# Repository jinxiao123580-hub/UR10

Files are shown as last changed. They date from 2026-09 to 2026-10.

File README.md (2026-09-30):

# UR10 视觉力觉抓取实验平台

UR10 CB3、Robotiq 二指夹爪、ATI Net F/T 与 Mech-Eye PRO XS 的课程与实验仓库。

**唯一的接手入口是 [`HANDOVER.md`](HANDOVER.md) 顶部的 `0A. 最新接手状态`。** 它覆盖旧
实验记录和历史文档中的结论。

当前版本为 `v2026.09.30`，上一版 `v2026.09.28` 仍保留；本次升级内容、验证边界和恢复说明见
[`docs/18-2026-09-30视觉抓取升级版.md`](docs/18-2026-09-30视觉抓取升级版.md)。

2026-09-24 的视觉自主抓取验收、相机依赖恢复和完整命令见
[`docs/17-视觉自主抓取验收.md`](docs/17-视觉自主抓取验收.md)。

## 仓库结构

| 位置 | 用途 |
|---|---|
| `scripts/` | 采集、规划、真机门禁与执行脚本 |
| `config/` | 标定、工具、附件与网络配置 |
| `ros2_ws/src/` | 数字孪生与 ROS 包完整源码 |
| `third_party/` | 外部 Mech-Eye ROS 包的固定版本补丁与恢复启动文件 |
| `docs/`、`HANDOVER.md` | 当前操作入口、限制与交接说明 |
| `outputs/` | 已版本化的原始数据、计划和实验验证证据 |

## 现在可直接使用

先阅读 [`docs/00-当前可用操作.md`](docs/00-当前可用操作.md)。其中只保留已验收的、当前
环境可运行的命令；所有运动都必须由单独的已验收实验方案授权。

```bash
cd ~/UR10
python3 scripts/diagnose.py
python3 scripts/verify_ur_payload.py
python3 scripts/monitor_ur_safety.py --duration 3
```

相机验证需单独启动相机终端（重启后重新执行）：

```bash
# 终端 A：启动 Mech-Eye
cd ~/UR10
source /opt/ros/humble/setup.bash
source ~/colcon_ws/install/setup.bash
ros2 launch ~/colcon_ws/src/mecheye_ros2_interface/launch/start_camera_ur10.py

# 终端 B：采集并保存验证数据
cd ~/UR10
source /opt/ros/humble/setup.bash
source ~/colcon_ws/install/setup.bash
python3 scripts/validate_mecheye_capture.py
```

## 当前边界

- 不执行电脑端流式 IK 真机运动。
- 不把未独立验证的 ATI 重力补偿用于控制或抓取判定。
- 不运行历史抓放脚本；其负载参数未验证。
- 相机图像虽有颜色话题名，但 PRO XS 的 2D 传感器是单色（硬件规格），实测 bgr8 三通道逐像素相同。
- 视觉物体中心尚未独立验收；已完成的抓放含人工修正，不是自主抓取。
- 保留的抓放示例是 [`scripts/position_pick_place.py`](scripts/position_pick_place.py)，仅为已确认点位的位置控制，不含力控；当前只通过 dry-run，尚未完成本机真机抓放验收。
- 固定点课程演示可显式使用 `--demo`；该模式忽略 `OBJ`，不代表抓取成功，完整重启后指令见 `docs/00-当前可用操作.md`。
- 夹爪实时反馈验证使用 [`scripts/verify_gripper_motion.py`](scripts/verify_gripper_motion.py)，不移动机械臂。

## 文档导航

| 文档 | 当前用途 |
|---|---|
| [`docs/00-当前可用操作.md`](docs/00-当前可用操作.md) | 已验证命令和禁用入口 |
| [`docs/01-硬件与网络.md`](docs/01-硬件与网络.md) | 硬件、网络和端口 |
| [`docs/02-官方ROS2驱动.md`](docs/02-官方ROS2驱动.md) | 官方 ROS 2 驱动启动与只读确认 |
| [`docs/04-夹爪控制.md`](docs/04-夹爪控制.md) | Robotiq ASCII 通道和状态解释 |
| [`docs/08-六维力与3D相机.md`](docs/08-六维力与3D相机.md) | ATI、Mech-Eye 接入和坐标约定 |
| [`docs/09-MechEye相机接入清单.md`](docs/09-MechEye相机接入清单.md) | 相机接入与采集验收 |
| [`docs/11-机器人自身标定.md`](docs/11-机器人自身标定.md) | TCP、负载和运动学标定 |
| [`docs/12-力传感器重力补偿.md`](docs/12-力传感器重力补偿.md) | 重力补偿的失败结论与限制 |
| [`docs/14-待办与已知问题.md`](docs/14-待办与已知问题.md) | 未完成项目的唯一清单 |
| [`docs/15-位置抓放展示流程.md`](docs/15-位置抓放展示流程.md) | 重启后固定点展示的完整终端指令 |
| [`docs/16-历史ROS桥抓放方法.md`](docs/16-历史ROS桥抓放方法.md) | 原样保留的旧 ROS 抓放命令，仅供历史对照 |

`experiments/` 和 `legacy/` 存放历史过程与失败实验，不是操作教程。新结论必须保存原始数据，
经独立验证后才写入 `docs/`。

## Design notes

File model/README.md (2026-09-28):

# 末端模型

本目录是 UR10 仓库中唯一的末端模型源，不依赖本机的 ROS 工作区路径。

| 路径 | 用途 | RViz 状态 |
| --- | --- | --- |
| `solidworks/end_effector/` | 用户从 SolidWorks 导出的完整末端装配：ATI 六轴力传感器、连接件、Robotiq 2F-85（闭合）和 Mech-Eye 相机 STL；另保留原始 STEP。 | 当前 CAD 可视化来源 |
| `collision/ur10_cell.collision.xacro` | 根据实测尺寸建立的简化包络碰撞模型。 | 仅供碰撞/间隙初步检查，不能作为真机安全判据 |
| `ur10/visual/` | UR10 本体七个 DAE 视觉网格副本，与当前 CAD RViz 使用的 URDF 视觉网格完全一致。 | 网页监控台实时模型来源 |
| `ur10/*.stl` | UR10 本体各连杆的碰撞网格副本。 | 离线碰撞/间隙检查备用 |

## 查看完整 CAD

```bash
cd ~/UR10
source /opt/ros/humble/setup.bash
source ~/colcon_ws/install/setup.bash
python3 scripts/build_urdf_with_cad_meshes.py
ros2 launch launch/view_ur10_preliminary_cad.launch.py
```

生成的 `outputs/vision/ur10_preliminary_cad_meshes.urdf` 和其中的 `cad_meshes/` 是可直接由 RViz 载入的副本；源文件始终在本目录。装配相对 `tool0` 的初版安装方向由 `config/robot_attachments.preliminary-cad-20260921.yaml` 固化，当前为已人工确认的 `tool_yaw_deg: 270`。

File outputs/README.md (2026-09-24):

# `outputs/` 证据与可复算数据

本目录保存实验运行产生的证据，不是临时缓存。路径被 JSON 计划和复算脚本引用，请勿随意改名。

| 目录 | 内容 |
|---|---|
| `handeye/` | 手眼标定数据集、图像、角点、同步机器人帧、原始点云与求解报告 |
| `vision/` | 物块识别、棋盘预检、悬停/主动视角原始点云、融合与抓放计划 |
| `ft_*`、`gripper/` | ATI 六轴力、夹爪状态和验证证据 |
| `dashboard/` | 运行时日志；不作为版本化实验输入 |

当前视觉自主抓取的验收入口和各文件含义见
[`../docs/17-视觉自主抓取验收.md`](../docs/17-视觉自主抓取验收.md)。

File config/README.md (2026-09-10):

# ATI gravity calibration data

Calibration date: 2026-09-10 (Asia/Shanghai)

## Files

- `ft_gravity_calibration.yaml`: accepted calibration generated from the last
  10 consistent poses. This is the file consumers should load.
- `ft_gravity_calibration.mixed-18.yaml`: all 18 persisted samples from both
  acquisition batches. It is retained as raw evidence; its combined fit is
  invalid because the first 8 samples are inconsistent with the later batch.
- `ft_gravity_calibration.invalid-20deg.yaml`: earlier 12-pose, 20-degree
  calibration result retained for comparison. It is invalid and must not be
  used for compensation.

## Accepted result

- Downstream mass: `3.2170005989 kg`
- Center of mass in `ft_sensor`: `[-0.0739583, 0.0746015, 0.0594935] m`
- Force bias: `[5.7368001, 7.2738515, 32.9430006] N`
- Torque bias: `[-0.2363989, -0.1070706, -0.2677242] N m`
- Force RMS residual: `0.7986392 N`
- Torque RMS residual: `0.0916483 N m`
- Design condition number: `9.4482`

The ATI hardware bias must remain zero. Gravity compensation must use the
software parameters above. The mass is the load below the sensing element;
it is not the total robot payload including the Net F/T sensor body.

The accepted result is a fit result. Validate it on poses not used by the fit
before enabling collision detection or force control.

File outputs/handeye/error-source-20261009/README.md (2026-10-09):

# 2026-10-09 固定棋盘格误差来源实验

本目录是供离线复算的原始实验记录，不是新手眼标定结果。实验期间棋盘格未移动（现场用户确认）；机械臂只作低速位移，未修改 DH、相机内参或手眼外参。标定文件仍为 `config/handeye_eye_in_hand_20260921.yaml`。

## 数据和顺序

| 顺序 | 数据集 | 有效样本 | 说明 |
| --- | --- | ---: | --- |
| 1 | `dataset.json` | 5 | 首个静止位姿，之后机械臂换位置和姿态 |
| 2 | `pose-change/dataset.json` | 3 | Y 平移实验的起点 A |
| 3 | `translation-only/dataset.json` | 3 | 从 A 纯平移约 +155.19 mm Y，姿态基本不变 |
| 4 | `return-to-pose/dataset.json` | 3 | 低速沿 Y 原路返回 A |
| 5 | `xminus-160/dataset.json` | 3 | 从 A 纯平移约 -159.97 mm X，姿态基本不变 |
| 6 | `x-return/dataset.json` | 3 | 低速沿 X 原路返回 A |

每个数据集旁的 `samples/<sample_id>/` 包含彩色原图 `image.png`、角点图 `corners.png`、原始有组织点云 `cloud.npz`、逐帧 UR 状态 `robot_frames.json` 和 `sample.json`。数据集 JSON 内的 `files` 字段保留采集电脑的绝对路径；在其他电脑上请按**数据集所在目录**寻找同名 `samples/`，不要使用旧绝对路径。仓库的 `scripts/analyze_handeye_closure.py` 已按相对目录读取点云。

## 已复算的观测值

- Y 起点到 +155.19 mm 位：OpenCV PnP 的固定棋盘格基座坐标差 1.420 mm、朝向差 0.3918°；原始深度角点刚体拟合位置差 1.672 mm、朝向差 0.078°。返回位与 Y 起点实际 TCP 相差 0.089 mm / 0.009°，PnP 位置差 0.542 mm，深度位置差 0.426 mm。
- X 起点到 -159.97 mm 位：实际 TCP 朝向差 0.007°；PnP 的固定棋盘格位置差 1.251 mm、朝向差 0.477°。返回位与 X 起点实际 TCP 相差 0.019 mm / 0.009°，PnP 位置差 0.158 mm、朝向差 0.032°，深度位置差 0.216 mm。
- X 侧视角仅约 35–36 个角点有可用深度，且点云角点一致性约 2 mm；该视角深度拟合**不可用于独立精度裁决**。原位三次重复的 PnP 板原点 RMS 通常约 0.008–0.032 mm，这只反映短时重复性，不等于绝对精度。

固定手眼平移在工具朝向不变的纯平移差分中抵消。固定手眼旋转误差可能造成跨视角位置误差，却不能单独解释工具朝向几乎不变时 PnP 棋盘格朝向变化约 0.4–0.5°。仍需核对相机模型、角点检测、深度配准、实体安装与棋盘格平面性；不要由这组数据直接修改 DH 或手眼参数。

## 在另一台电脑复算

从仓库根目录执行（不连接机器人）：

```bash
PYTHONNOUSERSITE=1 /usr/bin/python3 scripts/analyze_handeye_closure.py \
  --dataset outputs/handeye/error-source-20261009/xminus-160/dataset.json \
  --calibration config/handeye_eye_in_hand_20260921.yaml \
  --output outputs/handeye/error-source-20261009/xminus-160/recomputed-closure.json
```

将 `--dataset` 改为表中的其他五组即可；现有 `static-closure.json` 是采集机上的参考输出。对两组的 `static-closure.json`，比较 `board_geometry.reference_base_from_target.matrix_4x4` 的平移差和旋转夹角；不要把静止组内 RMS 当作跨视角误差。旧多姿态基线为 `outputs/handeye/error-source-baseline-20261009.json`，对应已归档的 `outputs/handeye/manual-eye-in-hand-20260921-r2.json`。

依赖为 Python 3、NumPy、OpenCV、SciPy 和 PyYAML。离线脚本不发送运动指令；`motion-result.json` / `return-motion-result.json` 是已经完成的低速返回记录，不应重放。

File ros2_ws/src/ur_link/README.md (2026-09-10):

# ur_link —— 最小 UR ROS2 桥（无需机械臂侧安装任何东西）

把 UR 控制器三个原生 TCP 接口包成 ROS2 节点，适合课程/实验室“先打通”场景：
CB3(固件≥3.5) 与 e-Series 均适用。要 MoveIt 实时规划控制请走官方
ur_robot_driver + externalcontrol URCap(需要示教器侧安装)。

## 接口
| ROS 侧 | 说明 | UR 侧 |
|---|---|---|
| `/joint_states` (sensor_msgs/JointState) | 6 关节 位置/速度/电流 | 30001 Primary @10Hz |
| `/ur_link/is_program_running`, `/ur_link/robot_mode`, `/ur_link/speed_fraction` | 运行/模式/速度系数 | 同上 |
| `ur_link/dashboard/power_on` 等 Trigger 服务 | power_on/brake_release/close_safety_popup/stop/pause/play/robotmode/... | 29999 Dashboard |
| `~/urscript` (std_msgs/String 话题) | 发任意 URScript | 30002 Secondary |

## 构建
```bash
cd ~/ros2_ws
colcon build --packages-select ur_link
source install/setup.bash
```

## 运行
```bash
# 实机
ros2 launch ur_link ur_link.launch.py robot_ip:=192.168.1.3
# 或分开跑：
ros2 run ur_link ur_state_node --ros-args -p robot_ip:=192.168.1.3
ros2 run ur_link ur_command_node --ros-args -p robot_ip:=192.168.1.3
```

## 用起来（示例）
```bash
ros2 topic echo /joint_states --once

# 上电+松刹车（机械臂旁必须有人按住急停随时准备）
ros2 service call /ur_link/dashboard/power_on std_srvs/srv/Trigger
ros2 service call /ur_link/dashboard/brake_release std_srvs/srv/Trigger

# 让它动：发 URScript(先载入任意程序并 play 才有程序上下文；或直接发脚本也会执行)
ros2 topic pub --once /ur_link/urscript std_msgs/String \
  "data: 'movej([0,-1.5708,0,-1.5708,0,0], a=1.4, v=1.05)'"
# 建议先加  sleep(0.5) 等待编译：
ros2 topic pub --once /ur_link/urscript std_msgs/String \
  "data: 'sleep(0.5)\nmovej([0,-1.5708,0,-1.5708,0,0], a=1.4, v=1.05)'"
```

## 离线自测（不需要机械臂）
```bash
python3 ~/ur_learn/scripts/fake_ur_server.py 0     # 模拟 127.0.0.1 的 UR
ros2 run ur_link ur_state_node --ros-args -p robot_ip:=127.0.0.1
ros2 topic echo /joint_states
```

## 注意
- 机械臂没上电/急停/保护性停止时，30002 发的运动命令会被忽略，先看 robotmode。
- e-Series 处于“本地(local)”模式时 30001/30002/30003 断开，改连 30011/30012。
- 老 CB3 固件(<3.5)没有帧头流，本包会退化为尽力解析，仍能读 q_actual。
- 速度/加速度给默认上限以内；始终有人在急停旁。

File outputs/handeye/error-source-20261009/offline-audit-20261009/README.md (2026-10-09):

# 固定棋盘格完全离线复算（2026-10-09）

输入提交：`0489e5d505f3924ae5eb9cd39b791f70de69646e`。20 个有效样本的原图、cloud.npz、sample.json、逐帧状态齐全；91 个输入文件逐一核对 Git blob 与 SHA-256。9512 帧机器人状态通过有限性及均值一致性检查。使用数据集旁 samples/<sample_id>，没有依赖旧 /home/jx 路径。

没有连接、移动机器人，也没有修改现有标定文件。冻结手眼 YAML SHA-256：`7fbd513c5f5b3cf2a9014a16ce5fda77543e12c889420abad3ae864e7665f153`。

## 主要结果

完整过程、误差传播及原始 SB 结果见 [初始报告](results/REPORT.md)，定位敏感性见 [补充报告](results/deeper/INTERPRETATION.md)，冻结参数和时间关联见 [决策报告](results/frozen/DECISION.md)。历史报告中的本机路径为当时运行记录；跨平台复现请用下方入口。

以下使用仅由前三组图像残差选出的 SB + cornerSubPix(9) 固定规则；是回顾性划分，不是未经查看的新数据验证，更不是绝对精度标定。深度为角点附近 7×7 有效 XYZ 中值的独立刚体拟合。单位为 mm / deg。

| 比较 | 控制器 TCP 平移/转角 | 基座棋盘 PnP 变化 | 基座棋盘深度变化 |
|---|---:|---:|---:|
| Y A→B | 155.189 / 0.00579 | 1.538 / 0.21418 | 1.636 / 0.06981 |
| Y A→返回 A | 0.0885 / 0.00907 | 0.471 / 0.04596 | 0.464 / 0.05052 |
| X A→B | 159.971 / 0.00725 | 0.526 / 0.08126 | 0.467 / 0.29352 * |
| X A→返回 A | 0.0190 / 0.00876 | 0.157 / 0.01098 | 0.142 / 0.03283 |

* X 侧视角原始检测仅 35–36 个角点有深度；冻结精化后为 35/35/35，约 59% 棋盘区域有深度。深度姿态对邻域尺寸高度敏感，不是可靠姿态真值。

六组 PnP 组内位置 RMS 为 0.025–0.050 mm，但重复性不代表绝对精度。近似同位姿的三簇在约 16.3 分钟内，PnP/深度分别变化 0.613/0.600 mm；线性时间关联约 0.0375/0.0368 mm/min。时间与运动历史混杂，不能认定热漂移。原图角点场也发生相应移动，不能仅归为 PnP 数值抖动。

### 支持、不能排除、已排除的边界

- 支持：角点定位方法会显著改变姿态推断；X 深度姿态不可靠；返回误差含图像与深度共同变化；当前姿态激励不足（平移外参相关矩阵条件数约 1497）。
- 不能排除：内参/成像偏差、深度上游配准或系统偏差、固定件或棋盘变化、时间/运动历史影响、手眼旋转误差、控制器真实运动学误差。没有外部真值，不能把其中某项确定为唯一原因。
- 已排除（限定范围）：输入缺失、旧绝对路径造成无法复算、归档状态均值计算错误、所核对 cloud XYZ→像素的额外缩放/转换错误。固定手眼平移误差不能单独解释这些近纯平移组的毫米级变化；不等于排除所有手眼误差。

## 最后一项纯数据补查：灰度边线交点

[edge-check.json](results/frozen/edge-check.json) 保留探索性检查：用现有角点只初始化局部方向，直接对灰度剖面求边缘，再拟合两条线并求交点，未调用 cornerSubPix，也未用基座闭合选择参数。

它与冻结角点相差 0.337–0.512 px，各组边线拟合 RMS 0.283–0.538 px，PnP RMS 0.205–0.352 px；Y/X 外移闭合变为 0.814/1.588 mm。这不是更准确的结果：边线估计自身残差大、受局部光度和窗口影响，且初始化并非独立真值。该检查未能提供足够精度的独立角点裁判，不能据此替换冻结结果或归因 DH。保留失败/不确定的检查，避免只报告有利算法。

现有数据还可以继续试检测器或联合拟合，但不会增加物理观测约束；在当前姿态激励、时间混杂和缺少独立真值的条件下，不能可靠分离手眼、运动学和共同成像/固定件误差。不建议继续以同一批闭合残差挑选“最优标定”。

## 可复现命令

先在可联网阶段准备 Python 环境并取得完整仓库；计算阶段完全离线，不运行采集/机器人程序。使用原分析版本可最大程度复现软件差异：Python 3.14.6、numpy 2.5.3、scipy 1.18.1、opencv-python-headless 5.0.0.93、PyYAML 6.0.3。也可用其他兼容版本，但必须记录差异。

```bash
python -m pip install numpy==2.5.3 scipy==1.18.1 opencv-python-headless==5.0.0.93 PyYAML==6.0.3
# 在仓库根目录运行；--work 必须是尚不存在的新目录。
python outputs/handeye/error-source-20261009/offline-audit-20261009/reproduce.py --repo . --work ../UR10-offline-reproduction
```

入口先校验 91 个输入 SHA-256，然后复制输入到新目录并依次运行全部独立复算、敏感性、冻结规则、时间与可辨识性检查。不访问网络，不导入 ROS，不写原始文件或标定。新目录约需 300 MB 空间；输出在 `../UR10-offline-reproduction/offline-audit-0489e5d/results/`。若原始输入被改动，校验失败即停止；请从指定提交恢复到独立副本后重试，不要覆盖个人改动。

仅校验：

```bash
python outputs/handeye/error-source-20261009/offline-audit-20261009/reproduce.py --repo . --work ../unused --verify-only
```

机器可读结果：[逐样本](results/frozen/sample-results.csv)、[往返比较](results/frozen/pair-results.csv)、[完整冻结计算](results/frozen/validation.json)、[时间关联](results/frozen/temporal.json)、[可辨识性](results/frozen/identifiability.json)。原始检测和深度邻域敏感性也全部保留在 results/。

## 下一步采集要求（仅建议，本次未执行）

先做 **15 分钟完全静止对照**，不需要精密仪器，也不需要移动机器人：

1. 固定机器人、相机、棋盘及支架；选深度完整的正视位置，不用 X 侧视角。保持当前标定、TCP 设置和相机参数，不重新标定、不重启、不自动更改曝光策略。
2. 每 30 秒保存一份，约 31 份；完整保存未标记原图、cloud.npz、camera_info、采样窗口全部机器人状态、图像/深度/状态时间戳及窗口起止时间。不要只留角点或平均位姿。
3. 能取得则额外记录曝光、增益、自动曝光开关、温度、TCP offset、关节位置和设备时钟。取不到的字段明确标为缺失，不要补零假装已知。记录是否触碰、振动、灯光变化。
4. 继续使用本文冻结检测规则，比较图像角点场、PnP、深度、机器人状态随时间的共同/分离变化，不以闭合误差重新调参。

若静止时 PnP 和深度共同漂移，优先检查固定件、热/时间及共同成像因素；仅 PnP 变则优先查二维定位/内参；仅深度变则优先查深度通道。若静止足够稳定，再另行安排多轮 Y A→B→A、交错采集及更充分转动激励，分离时间与运动历史。本次结果不授权执行任何机器人运动。

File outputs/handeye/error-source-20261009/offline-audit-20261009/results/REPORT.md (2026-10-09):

# 固定棋盘格误差源离线复算

后续已对同一数据继续定位角点精化、棋盘固定残差图样及点云射线关系，新增证据见 [进一步分析](deeper/INTERPRETATION.md)。原报告的 SB 结果保留作为原始处理链基线；后续处理结果并非新标定。

最新完成了固定参数验证、残差方向和时间关联分析，下一项采集的选择见 [固定方案验证与下一步决策](frozen/DECISION.md)。

已核对 GitHub `jinxiao123580-hub/UR10` 的主分支：获取时头提交为 `0489e5d505f3924ae5eb9cd39b791f70de69646e`，父提交 `055ab43d3b1a21df99e53db21bc084032fa7b80b`，提交说明为 `data: archive 2026-10-09 hand-eye error-source experiments`。本报告所有采集数据均固定到该提交。原有 `UR10` 工作树有未提交改动，未用于产生测量结果。

**结论：数据支持视角相关的角点/PnP 位姿偏差，也支持点云与 PnP 存在不一致；尚不能分离相机模型、棋盘实体几何、深度配准/偏置和实体安装变化。固定手眼平移及固定手眼旋转作为全部异常的唯一来源可排除，物理运动学绝对误差仍不能排除。没有依据修改 DH 或手眼文件。**

## 1. 输入完整性与复算方法

六组共 20 个 accepted 样本：全部 `image.png`、`cloud.npz`、`robot_frames.json`、`sample.json` 均齐全且可解码。原图全部 1280×1024；点云全部 1024×1280×3，有非有限点，但 NPZ 的所有成员均可解压，样本 ID 与数据集一致。9512 帧机器人状态的计数与各 JSON 声明一致，TCP 与关节角数值均有限。每个样本从逐帧 TCP 重算的六维算术均值与归档均值最大差为 0。机器人采样窗口内最大位置偏离均值为 0.04454 mm，最大相对首帧转角为 0.009743°；这些是采样窗口内状态变化，不能代表实体绝对定位精度。算术轴角均值和 SO(3) 均值的最大角差仅 2.77×10⁻⁸°，均值实现不是这里的误差源。

下载的 91 个文件（80 个样本文件及 11 个数据集/配置/源码文件）逐项计算 `SHA1("blob " + 字节数 + NUL + 文件内容)`，全部与指定提交的 Git 树对象一致。详见 `git-blob-verification.json`；SHA256 与大小见 `../download-manifest.json`。点云始终从各 `dataset.json` 同级的 `samples/<sample_id>/cloud.npz` 读取，未使用旧 `/home/jx/UR10/...` 路径。

使用冻结的 `config/handeye_eye_in_hand_20260921.yaml`：`tool0_T_camera` 为该文件的旋转矩阵和平移。文件 SHA256 为 `7fbd513c5f5b3cf2a9014a16ce5fda77543e12c889420abad3ae864e7665f153`；计算前后相同。

主结果的处理链：

1. 从原图重新调用仓库 `detect()` 的 OpenCV 棋盘检测逻辑，全部重新检出 9×6=54 个角点。归档角点仅用于消除棋盘对称的编号翻转，没有用来初始化检测或求解。格长 6 mm，原点为编号第一角点。
2. 使用每帧归档 CameraInfo 的 K 与 D（D 为五个零），独立运行 `SOLVEPNP_ITERATIVE`，重新投影并记录逐角点二维残差。
3. 从逐帧机器人 TCP 重算 A，计算 `C = A · X · B`。组内旋转用 SVD 投影到 SO(3)，平移算术平均。
4. 在每个重检角点周围半径 3 px 的 7×7 点云邻域取有效 XYZ 分量中位数，至少 3 个有效像素才保留该角点；从棋盘物点到这些 XYZ 用带 det=+1 约束的 Kabsch 刚体拟合得到 D，再计算 `C_depth = A · X · D`。拟合没有使用 PnP 的 rvec/tvec。
5. 使用经典 `findChessboardCorners + cornerSubPix` 作检测器对照、IPPE 作平面 PnP 分支对照；检查深度邻域半径 1/2/3/5 px；作 0.05 px 独立像素噪声蒙特卡洛与深度角点 bootstrap。

环境：Python 3.14.6、NumPy 2.5.3、OpenCV 5.0.0（包 5.0.0.93）、SciPy 1.18.1、PyYAML 6.0.3。没有导入/调用 ROS、机器人通讯或运动模块；仅从采集源码 AST 提取 `detect` 数学函数。

## 2. 六组重复性和深度质量

下表全部来自本次原图重检。PnP/深度重复性为各样本相对该组平均板位姿的 RMS，单位 mm/°；不是跨视角准确度。深度/PnP XYZ 差是在相机系比较同一角点位置，不依赖手眼。深度拟合 RMS 是拟合后的内部残差，也不是绝对准确度。

| 组 | 样本/状态帧 | 重投影 RMS 均值 px | PnP 重复性 mm/° | 有效深度角点 | 深度/PnP XYZ RMS mm | 深度刚体拟合 RMS mm | 深度重复性 mm/° |
|---|---:|---:|---:|---|---:|---:|---:|
| initial | 5 / 2023 | 0.2067 | 0.0490 / 0.0071 | 54/54/54/54/54 | 0.640 | 0.191 | 0.0666 / 0.0437 |
| pose-change，Y 起点 A | 3 / 1720 | 0.2998 | 0.0336 / 0.0086 | 54/54/54 | 1.283 | 0.281 | 0.0322 / 0.0651 |
| translation-only，Y 位 B | 3 / 1503 | 0.1682 | 0.0077 / 0.0077 | 54/54/54 | 1.027 | 0.154 | 0.0131 / 0.0231 |
| return-to-pose，Y 返回 / X 起点 | 3 / 1518 | 0.2948 | 0.0357 / 0.0266 | 54/54/54 | 0.953 | 0.252 | 0.0253 / 0.0319 |
| xminus-160，X 位 B | 3 / 1127 | 0.3257 | 0.0292 / 0.0439 | **35/36/36** | **1.993** | **0.512** | **0.0894 / 0.4725** |
| x-return，X 返回 | 3 / 1621 | 0.2917 | 0.0306 / 0.0387 | 54/54/54 | 0.962 | 0.262 | 0.0129 / 0.0347 |

所有单帧重投影 RMS 小于 0.5 px；最大单角点残差为 0.8352 px。低残差只能说明模型在这些观测上的内部拟合，不证明内参、板格长或位姿无偏。

六组 PnP 板原点平均位置（基座系 mm）：initial `[409.956,-56.161,-13.221]`；Y A `[409.939,-58.214,-13.628]`；Y B `[409.492,-58.236,-12.276]`；Y 返回 `[409.797,-58.446,-14.099]`；X B `[409.253,-59.397,-13.480]`；X 返回 `[409.763,-58.606,-14.127]`。完整朝向矩阵、法向、逐样本变换及角点残差可由 `audit.json` 的 `groups.C`、`samples.C`、`samples.residual_px` 复核。

首组到 Y 起点不是纯平移：控制器 TCP 变化 26.174 mm / 14.7945°，PnP 板变化 2.093 mm / 0.2967°，深度板变化 2.063 mm / 0.2272°。该段不能套用纯平移的手眼平移抵消结论。

## 3. Y 与 X 的 A→B→A

“实际 TCP”在这里严格指**采集时控制器报告的 TCP**，不是外部测量的实体真值。X 的 A 是 `return-to-pose`，不能错用早先 `pose-change`，两者已有返回残差。

| 路段 | TCP ΔXYZ mm | TCP 位移 mm / 转角 ° | PnP 板 ΔXYZ mm | PnP 板位置 mm / 转角 ° | 深度板位置 mm / 转角 ° |
|---|---|---:|---|---:|---:|
| Y A→B | [-0.039,+155.189,+0.046] | 155.189 / 0.00579 | [-0.446,-0.022,+1.352] | 1.424 / 0.3955 | 1.673 / 0.0819 |
| Y B→返回 A | [+0.0004,-155.157,+0.027] | 155.157 / 0.00492 | [+0.305,-0.210,-1.823] | 1.860 / 0.3137 | 1.779 / 0.1474 |
| Y A→返回 A | [-0.039,+0.032,+0.073] | **0.0885 / 0.00907** | [-0.142,-0.232,-0.471] | **0.544 / 0.0871** | **0.424 / 0.0656** |
| X A→B | [-159.971,-0.011,-0.048] | 159.971 / 0.00725 | [-0.544,-0.951,+0.620] | 1.259 / 0.4864 | **0.514 / 0.4310†** |
| X B→返回 A | [+159.980,+0.004,+0.032] | 159.980 / 0.00265 | [+0.510,+0.791,-0.648] | 1.143 / 0.4875 | **0.308 / 0.4238†** |
| X A→返回 A | [+0.008,-0.007,-0.016] | **0.0190 / 0.00876** | [-0.034,-0.160,-0.028] | **0.166 / 0.0378** | **0.219 / 0.0634** |

† X B 深度拟合不可靠，数值仅为诊断输出，不可据其较小位置差裁决 PnP、手眼或运动学的准确度。X A 和返回 A 各自均有 54 个有效角点。

板中心与板原点分开计算：Y 去程中心差 1.527 mm，X 去程 1.104 mm；返回中心差 Y 0.531 mm、X 0.167 mm。异常不是单纯选了边缘原点造成。

使用归档角点独立重新解 PnP 后，单样本相对归档的最大差仅 0.000131 mm / 0.000030°，复现 README 的 Y 1.420 mm / 0.391786°、深度 1.6715 mm / 0.078005°，X 1.2509 mm / 0.476544°；返回 PnP 残差为 Y 0.5420 mm / 0.099589°、X 0.1581 mm / 0.031531°，深度位置为 0.4257 / 0.2162 mm。本次原图重检与该结果的小差别主要来自检测器版本/角点变化，详见 `supplement.json`。仓库 `analyze_handeye_closure.py` 也对六组重新执行，输出保存为 `reference-*.json`；它使用归档位姿，不能替代原图重检。

## 4. 对误差来源的判别

| 候选原因 | 判定 | 数据依据与限制 |
|---|---|---|
| 视角相关的角点/PnP 系统偏差 | **支持** | 经典检测器的 X 去程板差变为 0.509 mm / 0.0625°，SB 为 1.259 mm / 0.4864°。X 经典重投影均值 0.1756 px，小于 SB 0.3257 px；Y 起点经典 0.1902 px，小于 SB 0.2998 px。仅换同一原图的角点处理便显著改变姿态，证明估计对检测方法敏感。仍没有经典角点的外部真值，不能宣称它准确或已解决全部误差。Y 经典去程仍有 1.483 mm / 0.2108°。 |
| 相机内参、未建模畸变、色图几何/配准 | **不能排除** | 六组 K 相同、D=0。0.05 px 独立像素噪声只产生约 0.047–0.089 mm / 0.027–0.053° 的单帧 PnP 敏感性，明显小于去程姿态变化；系统相关偏差可更大。共同焦距 +1% 将 Y 去程变为 2.086 mm / 0.3130°，径向 k1+0.01 将 X 去程变为 1.105 mm / 0.6177°。这是敏感性示例，不是这些内参真的错了；零 D 可能因为输出已校正，须核对图像管线。 |
| 深度质量及深度/PnP 不一致 | **支持存在限制** | 相机系角点 XYZ 差为 0.64–1.99 mm，不涉及手眼和机器人。它证明两条测量/模型链不一致，不能仅凭差值断定深度有偏而 PnP 正确。X 深度缺失非均匀，内部刚体残差 0.512 mm、组内角度 RMS 0.4725°，需特别降权。 |
| 深度误差作为全部 PnP 异常唯一原因 | **已排除（算法直接因果）** | 本次 PnP 仅用原图、K、D、棋盘格几何，不读深度。深度无法直接制造该 PnP 的角度变化；若色图生成/配准与深度共享上游处理，上游共同误差仍不能排除。 |
| 固定手眼平移作为纯平移段唯一原因 | **已排除** | 姿态固定时该平移严格抵消；实际姿态差仅 0.0058–0.0073°，即使手眼平移误差为 50 mm，其去程差分贡献也仅 0.0051–0.0063 mm，远小于 1.3–1.7 mm。它在 initial→Y A 的 14.8° 转姿段仍不能排除。 |
| 固定手眼旋转作为全部位置及朝向异常唯一原因 | **已排除“唯一原因”；位置贡献不能排除** | 约 0.5° 外参旋转误差作用于 155–160 mm 相对平移可产生约 1.35–1.40 mm 位置偏差。但同一固定旋转不能消掉近乎固定工具姿态下的板朝向差，数学下界见下一节。 |
| 机械臂实体运动学/绝对定位误差、关节回差、负载挠曲 | **不能排除，尚无独立支持足以定责** | TCP 和 q 都来自控制器，不能互相构成外部真值。返回 TCP 很近说明报告位姿返回较好，不能证明去程实体平移/朝向正确。采集窗口内微动很小，不支持明显运动中采集；静止安装挠曲或模型偏差仍可能。 |
| 本地标称 DH 被软件误用生成这次闭环 | **已排除该实现路径** | 采集器把控制器 TCP 均值直接转矩阵；本次闭环也直接使用归档 TCP，没有调用本地 DH/FK。控制器内部运动学的实体准确度仍未知。 |
| TCP/tool0 定义、安装微动、棋盘不平/格长不准/热漂移 | **不能排除** | `robot_frames.json` 明确记录控制器 TCP 定义；采集器却直接命名为 `base_to_tool0`，未保存当时 TCP offset 的独立证明。若有固定偏置，它会折入等效外参，在恒定朝向差分中仍抵消，不能单独解释朝向差；跨朝向段可有影响。实验以现场“板未移动”为前提，没有实体平面度、6 mm 格长溯源或安装位姿计量。 |
| 旧电脑绝对路径、文件缺失、单位/矩阵重算错误 | **已排除本次实现** | 相对路径读取成功，91 个输入 blob 完全一致，20 个样本完整解码，逐帧均值精确重现，归档角点独立 PnP 重现至数值精度。 |

## 5. 误差传播与深度可信度

令 `A=(R_A,t_A)`、`X=(R_X,t_X)`、`B=(R_B,t_B)`，板原点为 `p=t_A+R_A t_X+R_A R_X t_B`。手眼平移误差的跨帧贡献为 `(R_A2-R_A1) δt_X`，上界为 `2 sin(Δθ_A/2)||δt_X||`。纯平移时为零。故不能从本实验的平移闭环残差反向估计手眼平移。

固定 R_A 时，手眼旋转误差的平移敏感性约为 `||Δt_B|| δθ_X`；约 0.5° 可以产生毫米级残差，但这是可解释能力，不是外参误差的证据。Y 相机估计平移长度与报告 TCP 长度仅差 +0.0248 mm；X 差 -0.4874 mm。固定旋转保长度，不能在理想纯平移条件下消掉长度差；实际 R_A 小幅变化及相机距离形成的小量需计入，所以该长度差提示尺度/视角/实体运动误差，也不能专门归于 DH。

对朝向，旋转测地距离满足：`d(R_C1,R_C2) ≥ d(R_B1,R_B2) - d(R_A1,R_A2)`，固定 X 的左乘/共轭不会改变角距离。Y 原图 PnP 相机板朝向差 0.39460°，工具差 0.00579°，任何固定手眼旋转下板闭环角差至少 **0.38880°**；X 至少 **0.47369°**（0.48094°−0.00725°）。所以仅重调固定外参无法让这套 SB PnP 数据的板朝向一致。剩余角差必须在相机估计、报告/实体工具姿态不符、安装变化或实体板变化中寻找。

0.05 px 独立零均值像素扰动试验是条件敏感性，不是经标定的置信区间；实际重投影残差可能相关，不能直接当成独立角点噪声。深度 bootstrap 也只评估所见角点内部抽样敏感性，不包含统一深度偏置、图像配准偏置和棋盘形变。两条链共享 K、角点位置与板物点，因此深度对照是不同测量通道，并非完全无共同误差的计量真值。

X 深度尤其不稳：半径 1/2/3/5 px 下，X 去程深度朝向差为 **0.674/0.654/0.431/0.377°**，位置差 0.467/0.468/0.514/0.567 mm；单帧邻域调整引起的朝向变化最高约 **0.851°**。角点 bootstrap 单帧角度 RMS 为 **0.301/0.678/0.718°**。相比之下，Y 去程深度位置在这些邻域下为 1.655–1.675 mm，较稳定，朝向为 0.065–0.106°。X 缺失主要集中在棋盘部分列，虽总覆盖跨度仍为 48×30 mm，却非均匀覆盖；不能把“仍有三十多个点”视为充分条件。

IPPE 的低残差分支与迭代 PnP 接近，另一个分支在这些图上的 RMS 至少 0.9408 px，且姿态差数十度；不支持简单的 180° 编号反转或另一个平面分支被误选为这里约 0.4–0.5° 异常的解释。格点局部化、相机模型和实体板几何的连续偏差仍需检验。

Y 返回板残差约 0.54 mm、X 约 0.16 mm，超过许多组内重复性，但不等于绝对准确度，也不独立证明回差：图像/深度漂移、TCP 实体与报告不符、热/安装变化均可造成。每组仅 3 帧（首组 5 帧），不能把短时 RMS 除以根号样本数后宣称已排除系统误差。

## 6. 可复现命令与产物

文件均位于 `D:\项目\机械臂` 下。数据和依赖下载完成后，以下命令只使用本地文件，重算过程无网络、无硬件连接：

```powershell
Set-Location 'D:\项目\机械臂'
python audit_verify.py
python audit_recompute.py
python audit_supplement.py
python audit_reference.py
python audit_export.py
```

`audit_recompute.py` 会覆盖本审计自身的 `results/audit.json` 与 `partial.json`，不修改标定或采集文件。`audit_supplement.py` 输出 `supplement.json`，`audit_reference.py` 输出独立目录中的 `reference-*.json` 和日志。主要依赖已局部安装在 `offline-audit-0489e5d/python-deps`，没有修改全局 Python 环境。

在另一台电脑上先复制本审计目录或按固定提交重新获取数据；若需要安装依赖：

```powershell
python -m pip install --target '.\offline-audit-0489e5d\python-deps' numpy==2.5.3 scipy==1.18.1 pyyaml==6.0.3 opencv-python-headless==5.0.0.93
python audit_download.py
```

`audit_download.py` 是获取阶段工具，当前使用这台电脑已有的 `127.0.0.1:7897` 代理，其他电脑需调整该获取选项。获取阶段与完全离线复算分开；复算脚本不联网。Git blob 校验脚本需要本次隔离仓库中的提交树，也可在任意包含该提交的仓库中改 `repo` 路径。完整数据到齐的标志为 `download-manifest.json`；缺失时脚本等待获取完成而不会跳过样本。

## 7. 下一项最有判别力的实验

**固定机器人与相机，用外部计量的刚性平面棋盘在精密位移台上作板的 A→B→A，复现本次 Y/X 的相对相机视角与图像区域。** 这是建议，未在本次执行。

让棋盘沿与原机器人运动相反的实测向量移动，尽量复现本次的相对距离、视角、图像区域；用量块/位移台和独立 6D 计量确认板的真实平移及转角，棋盘先检查平面度和格长。固定同一 K/D 与色图处理，同时记录 SB、经典角点和深度，增加同位姿重复并交错采集 A/B 以控制时间漂移。精度宜达到 ≤0.05–0.1 mm、≤0.02°，以分辨本次毫米级和约半度的效应。

此时直接比较 `camera_T_board` 与外部测量，不需要手眼和机器人运动学。如果相同图像区域仍出现原有朝向/尺度偏差，便支持相机/角点/板模型；若只深度偏离则支持深度通道/配准；若 SB 与经典分歧重现，优先定位角点局部化；若偏差不重现且外部板计量可信，再进行跟踪实体法兰/相机安装的机器人 A→B→A 计量，以区分运动学与安装挠曲。一次阴性结果也要确认已复现相对成像几何，不能直接宣布相机被排除。

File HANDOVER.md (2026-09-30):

# 交接文档 · UR10 视觉力觉抓取系统

最后更新：2026-09-30。本文只保留当前可用状态；原始数据、失败实验和历史过程在
`outputs/`、`experiments/` 与 `legacy/`。

## 0A. 最新接手状态

### 2026-09-30 升级版本

- 当前标签 `v2026.09.30`，旧版 `v2026.09.28` 保留；详见 `docs/18-2026-09-30视觉抓取升级版.md`。
- 一次完整自动抓取与原始 Fz 接触式放置曾执行完成；另一轮持物到达棋盘上方后因力订阅启动收不到样本而在下降前停止。力采样等待已修复且只读测试通过，尚未复验真机放置。
- 初始定位支持棋盘分块检测与扩大搜索，悬停复拍采用局部点云，转运按物块/棋盘朝向规划并检查模型路径。固定 0.400 m 抓放距离门限已移除；未建模外部障碍仍需现场确认。
- 若仍夹持物块停在棋盘悬停位，不要重跑整套抓取；使用 `scripts/finish_held_cube_place.py` 的持物续放入口，并由脚本复核夹爪状态与位姿。

### 2026-09-24 视觉自主抓取验收（当前入口）

- 当前自动入口为 `FASTDDS_BUILTIN_TRANSPORTS=UDPv4 python3 scripts/auto_cube_pick_place.py --execute`；
  完整前置项与命令见 `docs/17-视觉自主抓取验收.md`。它会先复拍物块；首次/复拍不一致时使用
  三视角点云复核，而不是直接按首次棋盘定位下降。
- 夹取点是用户实测的 tool0 `+Z` 220 mm 夹取中心；当前策略对准**点云物块顶面上方 25 mm**。
  本轮 Robotiq 返回 `OBJ=2` 后才执行搬运。
- 放置为原始 ATI `Fz` 接触式：安全高度起始、2 mm 步进、相对基线突变 `>=8 N` 时 stopj、张开、
  抬离。2026-09-24 实测在第 18 步触发 `10.24 N`，已完成释放和离开；这不使用未验证的重力补偿。
- 棋盘格检测新增抗栅格干扰的裁剪放大回退；预检证据
  `outputs/vision/checkerboard-preflight-fixed-20260924/result.json` 为 54/54，RMS 0.253 px。
- 相机 ROS 的本机直连补丁和启动文件已归档在 `third_party/mecheye_ros2_interface/`；厂商 SDK 2.5.0
  是不可随仓库再分发的外部前置项，恢复脚本为 `scripts/bootstrap_mecheye_workspace.sh`。

### 设备与环境

| 项目 | 当前值 |
|---|---|
| 主机 | Ubuntu 22.04，ROS 2 Humble，用户 `jx` |
| UR10 CB3 | `192.168.1.3`，URSoftware `3.15.8.106339` |
| ATI Net F/T | `192.168.1.2`，RDT UDP `49152`，只允许一个消费者 |
| Mech-Eye PRO XS | `192.168.1.33`，SDK `2.5.0` |
| Robotiq | 机器人 `192.168.1.3:63352`，电脑直控 ASCII |

### 已独立验证的结论

- 官方 `ur_robot_driver 2.14.0` 可在 ROS 2 Humble 启动；工厂运动学文件为
  `config/ur10_factory_calibration.yaml`。录制姿态的 FK 对控制器 TCP 最大偏差
  `0.017312 mm / 0.004694°`；机器人基坐标必须使用 `base`，不能使用 `base_link`。
- Eye-in-hand 棋盘格标定使用 `10×7` 方格、`9×6` 内角点、格长 `6 mm`。Park 解在
  5 个留出样本的闭环 RMS 为 `2.642 mm / 1.051°`，最大 `3.855 mm / 1.837°`；冻结后
  一组独立样本为 `2.614 mm / 0.401°`。参数在
  `config/handeye_eye_in_hand_20260917.yaml`。
- 图像 PnP 与组织点云逐角点验收 54/54 有效，XYZ RMS `0.692 mm`、P95 `1.197 mm`、
  最大 `1.332 mm`。
- ATI 原始数据稳定发布到 `/ft_sensor/wrench_raw`，约 200 Hz；UR 30003/30013 状态约
  125 Hz。Mech-Eye 采集接口正常，但所谓颜色图和纹理点云实测均为单色。
- 一次物块抓起、提升和原位放回曾通过，但使用的是“视觉候选 + 人工修正”。视觉候选到
  人工确认中心的 XY 偏差为 `35.84 mm`，因此自主视觉抓取尚未通过。
- 当前保留的位置式抓放示例为 `scripts/position_pick_place.py`，使用控制器原生 `movel`
  和 Robotiq ASCII，不使用 ATI 或重力补偿；`config/position_pick_place.example.json` 中的
  点位仅用于离线示例。当前只通过 dry-run，尚未完成本机真机抓放验收，真机执行前必须现场重新确认。
- 已完成夹爪独立开合反馈验证：空夹 `POS=3 → 22 → 103 → 191 → 230`，张开回到 `POS=3`，
  目标闭合为 `PRE=255`；完整记录在 `outputs/gripper/motion-verification.json`。
- 2026-09-18 完成一次位置抓放闭环；闭合反馈为 `POS=229 / OBJ=3`，用户现场确认实际夹住后，
  继续完成抬升、搬运、释放和离开。该证据证明位置运动链可执行，但不构成自动 `OBJ=2` 验收。
- `scripts/position_pick_place.py --demo` 是固定点课程演示模式：显式忽略 `OBJ` 并继续位置流程；
  不得把演示结果写成抓取成功，也不使用力控。重启后的完整命令在 `docs/00-当前可用操作.md`。
- 课程展示的完整三终端流程已整理到 `docs/15-位置抓放展示流程.md`。

### 当前严格禁止

- 不执行电脑端流式 IK 真机运动；此前 2 mm 流式实验触发 `C153A0` 保护停。
- 不把 ATI 重力补偿用于力控、碰撞停止或抓取判定。所有现有重力模型均为 `valid: false`；
  新数据只用 `/ft_sensor/wrench_raw`。
- 不运行历史抓放程序；它含未独立验证的 `8.0 kg / [-0.03, 0.03, -0.06]` 负载估计。
- 不把控制器回读的 `3.5 kg / [0, 0, 0.1] m` 当作独立测量结果。
- 不把 Mech-Eye 的颜色话题当作真彩色：PRO XS 的 2D 传感器是单色，属硬件规格而非故障，
  `/mechmind/color_image` 的 bgr8 三通道由 SDK 按 `Blue = Gray, Green = Gray, Red = Gray`
  复制而来。型号证据见 `outputs/camera/model-identification-20260918.json`。

### 当前可直接执行的只读检查

```bash
cd ~/UR10
python3 scripts/diagnose.py
python3 scripts/verify_ur_payload.py
python3 scripts/monitor_ur_safety.py --duration 3
python3 scripts/read_ur_state.py
python3 scripts/check_current_docs.py

# 离线分析（不需要相机/机器人）
python3 scripts/analyze_ft_mass_scale.py          # P0-A：质量尺度 vs 常量力偏置（只读传感器 HTTP + 存档数据）
python3 scripts/analyze_cube_center_error.py      # P0-B：中心误差差向量 + 相机侧符号检查
python3 scripts/test_measure_cube_geometry.py     # 视觉几何离线数值门禁（6/6）
```

相机验证需另开终端（重启后重新执行）：

```bash
# 终端 A
cd ~/UR10
source /opt/ros/humble/setup.bash
source ~/colcon_ws/install/setup.bash
ros2 launch ~/colcon_ws/src/mecheye_ros2_interface/launch/start_camera_ur10.py

# 终端 B
cd ~/UR10
source /opt/ros/humble/setup.bash
source ~/colcon_ws/install/setup.bash
python3 scripts/validate_mecheye_capture.py
```

完整的当前入口见 [`docs/00-当前可用操作.md`](docs/00-当前可用操作.md)。

### 网页监控台（2026-09-18 修复启动/停止语义）

`bash scripts/start_dashboard.sh`（**必须先 `cd ~/UR10`**，脚本用的是相对路径）
起桥 + ATI（+ 可选相机），起完会**自检 `http://127.0.0.1:8080/` 真的应答**才打印地址，
否则打印端口占用与桥日志尾部并以退出码 1 结束。停止用
`bash scripts/start_dashboard.sh --stop`：SIGTERM → 最多 3 s → SIGKILL，并**校验 8080/9090
已释放**才报成功。修复前 `ros_web_bridge.py` 会吃掉 SIGTERM/SIGINT（`rclpy.spin` 在守护线程）、
`--stop` 打印"已停止"却留着进程占端口、启动脚本只看 `pgrep` 不看端口 → 页面"打不开"。
详见 `experiments/2026-09-18-入口可用性审计.md` §3.1。

## 课程进度（机械臂工程实践 8 节）

本轮做**第 1–6 节**；第 7（转盘动态抓取）、第 8（毛笔字）延后，且不采购新硬件。
第 4 节用闭合并拢的**左夹爪指尖代替笔尖**。完整方案与逐节做法见
[`experiments/2026-09-18-八节课实施计划草案.md`](experiments/2026-09-18-八节课实施计划草案.md)。

| 课 | 状态 |
|---|---|
| 1 整体认识 | ✅ 设备清单 + 三条通道已写入 [`docs/01`](01-硬件与网络.md) §7 |
| 2 示教器运动 | ✅ `scripts/read_ur_state.py` 已真机只读实测；示教器操作见 §8 |
| 3 ROS 控制运动 | ⏳ 入口已有（`scripts/position_pick_place.py`，**仅 dry-run**）；阻塞在负载未验证 |
| 4 关节标定 | ⏳ TCP 脚本就绪未采集；100.5 mm 直线实验未做 |
| 5 机器人感知 | ⏳ P0-A（力标定 2 倍矛盾）**已诊断**：是单姿态反推忽略常量力偏置的假象，传感器/换算无误；
  修复与绝对尺度基准**按用户决定延后**；时延测量仍未做 |
| 6 视觉自动抓取 | ⏳ 几何方案已换为"测顶面"并带离线门禁（6/6 通过），但**现场未验收**；
  旧的 35.84 mm 参照本身不成立（见 P0-B） |
| 7 转盘动态抓取 | 延后（现有相机 3D 采集 0.7–1.1 s，慢的是 3D 不是 2D，见计划 §5） |
| 8 毛笔字 | 延后（依赖第 4、5 节） |

## 两个必须先解决的问题 —— 均已定位（2026-09-18 当日做完）

### P0-A · 力标定的 2 倍质量矛盾 —— **已诊断为方法学假象，修复延后**

原问题：6 次独立拟合的质量一致收敛到 **3.20–3.29 kg**，而 2026-09-10 单姿态 `|F|/g` 反推
**6.56 kg**，相差 **2.03 倍**且可重复。

**结论（有数值证据）**：单姿态反推**忽略了传感器系内约 25–36 N 的常量力偏置**，
"`|F|` 与姿态无关且等于 `m·g`"这个前提本身不成立。

- 传感器只读配置（HTTP `192.168.1.2/netftapi2.xml`）：`cfgcpf = cfgcpt = 1000000`
  ⇒ `scripts/ati_netft_node.py:49-50` 的硬编码值**等于该传感器自己的标定值**，单位无误；
  `setbias = 0;0;0;0;0;0` ⇒ 硬件 Bias 全零，"错误 Bias 导致翻倍"不成立；量程 `165/165/495/15/15/15`。
- 68 个存档静态姿态的球面拟合（`F` 必落在半径 `m·g`、球心 `b` 的球面上，**不用 FK、不用安装旋转**）：
  6 个批次独立给出 **m = 3.14–3.51 kg**、`|b| = 24.8–35.8 N`，与既有多姿态拟合一致。
- 否证纯尺度错误：若真是 2 倍尺度错，`|F|` 必须恒定；实测 `|F|` 跨 **12.34–69.58 N（5.64 倍）**，
  单姿态法给出的质量在 **1.26–7.10 kg** 间摆动。

证据：`outputs/ft_calibration/mass-scale-diagnosis-20260918.json`、
`experiments/2026-09-18-力标定2倍质量矛盾诊断P0-A.md`；复现 `python3 scripts/analyze_ft_mass_scale.py`。
**仍开放（延后）**：① ~29.6 N 常量偏置的物理来源未定（零点/线缆侧向力/安装预载/配置残留）——
它不改变尺度结论，但直接违反"无外力应读零"；② 绝对牛顿尺度仍依赖质量基准，
控制器回读 `3.5 kg` 只是旁证、按本文规定不算独立测量。

### P0-B · 第 6 节视觉中心误差 —— **假设被否证，查出 50 mm 符号错误，改为"测顶面"**

原假设：`√(25²+25²) = 35.36 mm` 与实测 35.84 mm 只差 0.48 mm ⇒ 推测"两轴各偏半边长"。

**实测差向量否证该假设**：base 差向量 `(+31.36, -17.36) mm`（模长 35.84 mm），
在棋盘格系是 `(36.22, 13.94) mm` —— 只有模长巧合，分量根本不是 25/25。

**查出的硬错误**：可见竖直侧面在 target `x = +0.0528 m`，而相机原点在 target `x = +0.3641 m`
且光轴朝 `-x` ⇒ 凸体只露朝向相机的面，体心必须在**另一侧**（`x = 0.0278 m`）；
旧 `scripts/locate_cube_near_checkerboard.py` 用"远离棋盘格中心"判方向（本场景物块是沿 **-y** 偏
~110 mm 摆放，该启发式无意义）⇒ **符号反了 50 mm**。另外"50 mm 边长先验"从未被测量验证
（可见侧面 y 实测跨度仅 44.28 mm）；与人工确认点残差在符号修正后仍有 **22.2 mm**，
且与"50 mm 立方体 + 单可见侧面"几何上不自洽 ⇒ **那个人工目测点不能当验收基准**。

**修法已实现**：`scripts/measure_cube_geometry.py`（顶面平面 + 最小外接矩形足印 + 参考站立面，
带硬门禁：覆盖率 ≥0.85、与棋盘格面平行 ≤12°、长宽比 ≤1.10、点数下限；不满足**拒识**；
实测边长 ≠ 标称时单独报 `measured_size_prior_mismatch`；支持原始点云落盘与离线复算）。
离线数值门禁 6/6 通过（含"掠射视角只见侧面**必须拒识**"）：
`python3 scripts/test_measure_cube_geometry.py`。
证据：`experiments/2026-09-18-视觉中心误差差向量诊断P0-B.md`、`outputs/vision/center-error-diagnosis-20260918.json`。
**仍未验收**：需现场采集（**必须落盘原始点云**）+ ≥3 个重新摆放位置的**独立真值**比对。

## 已排除，不要再查（省时间）

| 嫌疑 | 结论 |
|---|---|
| 点云单位 mm/m 混用（1000× 错误） | **排除**：实测 `xyz_median ≈ 0.259`，与工作距离 0.3–0.6 m 同量级 ⇒ 是米 |
| 米制尺度完全未验证 | **部分已验**：6 mm 格长即独立长度基准，"逐角点 RMS 0.692 mm"已把尺度误差约束到 ~1.4%；缺的是全视场量程的独立基准 |
| 用了非官方 ROS 驱动 | **排除**：官方英文文档话题表漏了 `color_image` 是**笔误**；中文页与源码均确认该话题是官方的 |
| `base` 与 `base_link` 相差 1.182 m 是平移 | **改为**：UR 官方《Robot Frames》明确两者**同位置、仅绕 Z 轴转 180°**；180° yaw 使半径 r 处点位移 **2r**，r≈0.591 m ⇒ 正好 1.182 m。现场 `tf2_echo base base_link` 可确认 |

## 下一步（按顺序）

1. **P0-A 已诊断、按用户决定延后**：2 倍矛盾是单姿态反推忽略 ~29.6 N 常量力偏置的假象，
   尺度无需修正。延后的是"偏置的物理来源"与"绝对牛顿尺度的独立质量基准"。
2. **P0-B 已定位并实现修法**：下一步是**现场验收**——同一帧看到棋盘格与物块采集并落盘原始点云，
   在 ≥3 个重新摆放位置用独立真值比对（`scripts/measure_cube_geometry.py --capture --save-cloud`）。
3. **时延测量**：全库 grep `延迟|时延|latency|时间同步|时间戳对齐` **零命中**，
   而第 5 节明确要求"特别注意数据时间上的延迟"。
4. 第 4 节：TCP 标定 → 100.5 mm 直线实验
   （⚠️ 纯平移的 `movel` 下，TCP 定义误差**不改变**笔尖位移量 —— 该实验检验的是**运动学精度**，不是 TCP 定义）
5. 第 5 节：重力补偿重新建模 + 独立验收。⚠️ **原计划的门禁要改**：
   "拟合质量须与单姿态 `|F|/g` 一致（<5%）"**数学上无效**（单姿态法忽略了偏置，见 P0-A），
   应改为"未参与拟合的多姿态残差 + 姿态方向覆盖（可辨识性）"双门禁。
6. 第 6 节：P0-B 的几何修法 → 多位置中心误差验收（独立真值）→ 才可接自动抓取
7. **相机服务待定性**：2026-09-18 实测 `/device_info`、`/capture_color_image` 与
   `scripts/validate_mecheye_capture.py` 均无响应（40–60 s 超时，重启相机节点无效），
   相机硬件与 ROS 服务机制本身正常；需在**普通终端**复核一次再定性，见
   `experiments/2026-09-18-入口可用性审计.md` §3.2。

所有新的运动方案遵循：资料依据 → 离线数值门禁 → 官方假硬件 → 单段低速真机 → 完整流程。
每一层保存数值证据。

## 资料与存档规则

- 所有结论必须有数值证据；失败实验写 `experiments/`，原始 CSV/JSON 写 `outputs/`。
- 只有独立验证通过的稳定结论才能写入 `docs/`。
- 更新脚本、接口、路径或有效操作方式时，同一提交中更新 `docs/00-当前可用操作.md`、本文件和
  相关专题文档，并运行 `python3 scripts/check_current_docs.py`。
- 新方案实施前先查官方文档、论文或原始实现，记录来源、版本、适用条件及本机差异。

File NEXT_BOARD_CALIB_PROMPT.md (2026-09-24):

# 新会话用 Prompt：UR10 眼在手上棋盘格标定（重标 + 独立验收）

> 用法：把下面 `===== PROMPT 开始 =====` 与 `===== PROMPT 结束 =====` 之间的全文
> 复制到新对话里作为第一条消息。它是自包含的：新会话不需要看这段对话的历史。

===== PROMPT 开始 =====

我在做 UR10 机械臂工程实践课程的第 5 节（机器人感知），本轮任务是**眼在手上（eye-in-hand）
棋盘格手眼标定：重新标定 + 独立验收**。请先只读摸清现状，再按下面的门禁推进。

## 0. 先读这三个文件（不要假设旧文档里的"已完成"仍然有效）

1. `~/UR10/HANDOVER.md` 顶部「0A. 最新接手状态」——**唯一权威状态**，含「当前严格禁止」清单；
2. `~/UR10/docs/00-当前可用操作.md` —— 当前可执行入口；
3. `~/UR10/experiments/2026-09-18-视觉中心误差差向量诊断P0-B.md` —— 视觉几何的已知错因（必读，
   里面那条 50 mm 符号错误很容易在新代码里重犯）。

## 1. 设备与已验证现状

| 项目 | 值 |
|---|---|
| 主机 | Ubuntu 22.04 + ROS 2 Humble，用户 `jx`，仓库 `~/UR10` |
| UR10 CB3 | `192.168.1.3`，URSoftware `3.15.8.106339` |
| Mech-Eye PRO XS | `192.168.1.33`，SDK `2.5.0`，SN `RAM35238A3020004`（**2D 传感器是单色**，`/mechmind/color_image` 是灰度复制，不是故障） |
| ATI Net F/T | `192.168.1.2`，RDT UDP `49152`，**单消费者**（同时只能一个实例收流） |
| 棋盘格 | `10×7` 方格、`9×6` 内角点、格长 `6 mm` |
| 已有标定 | `config/handeye_eye_in_hand_20260917.yaml`（Park 解，`tool0_from_camera`，15 训练 + 5 留出；留出闭环 RMS `2.642 mm / 1.051°`，最大 `3.855 mm / 1.837°`；冻结后独立样本 `2.614 mm / 0.401°`） |
| **棋盘格位置** | **今天（2026-09-18）已被移动过** ⇒ 旧标定的绝对坐标不再对应现场，必须重标 |
| 机械臂位姿 | 当前 TCP ≈ `(0.647, -0.268, 0.276) m`，看不到旧场景；需要现场用**示教器**把臂点动到能同时看到棋盘格与物块的位姿 |

## 2. 硬性约束（违反即停）

- **禁止**电脑端流式 IK 真机运动（历史上触发过 `C153A0` 保护停）。
- **禁止**运行历史抓放程序（含未独立验证的 `8.0 kg / [-0.03,0.03,-0.06]` 负载估计）。
- **禁止**把 ATI 重力补偿用于力控、碰撞停止或抓取判定（所有现有模型 `valid: false`）。
- **禁止**把控制器回读的 `3.5 kg / [0,0,0.1] m` 当作独立测量结果。
- ATI 需要 RDT 数据时只允许**一个** `scripts/ati_netft_node.py` 实例；仪表盘在跑就会占着流。
- 真机运动前的顺序：**资料依据 → 离线数值门禁 → 官方假硬件 → 单段低速真机 → 完整流程**，
  每层保存数值证据。
- 采集期间机器人必须**静止**：脚本自带门禁 `max_position_motion_mm ≤ 0.5`、
  `max_rotation_motion_deg ≤ 0.2`，超限必须丢样本重采。
- 证据规则：**失败写 `experiments/`，原始 CSV/JSON/点云写 `outputs/`，只有独立验证通过的
  稳定结论才进 `docs/`**。
- **可能有另一个 agent 在同一仓库并行工作**：开工前跑 `git log --oneline -5` 与
  `ps aux | grep -E "codex|ros2|python3"` 看一眼；若它在给机器人发指令，**不要同时动**；
  也避免与它同时改 `HANDOVER.md` / `docs/00` / `README.md`（今天的提交就是它做的）。

## 3. 开工前必须先做的三项检查（全部只读）

```bash
cd ~/UR10
python3 scripts/diagnose.py                     # 网络/端口/模式，期望全绿
python3 scripts/read_ur_state.py                # 期望 robotmode RUNNING / safetystatus NORMAL
python3 scripts/check_current_docs.py           # 结束时也要跑
```

**相机链路必须先确认（今天已知异常）**：我在 2026-09-18 实测
`ros2 service call /device_info`、`/capture_color_image` 与
`python3 scripts/validate_mecheye_capture.py` 全部**超时无响应**（40 s / 60 s），
重启相机节点无效；相机硬件本身正常（SDK 日志显示已连上相机并打印型号/序列号），
ROS 服务机制也正常（本地自检服务可正常应答）。见
`experiments/2026-09-18-入口可用性审计.md` §3.2。存在两种可能：真实链路故障，
或仅是我那次运行环境（只读沙箱，SDK 报 `No write permission for directory /var/log/`）导致。

所以你要做的第一件事是**在普通终端复现**：

```bash
# 终端 A
cd ~/UR10 && source /opt/ros/humble/setup.bash && source ~/colcon_ws/install/setup.bash
ros2 launch ~/colcon_ws/src/mecheye_ros2_interface/launch/start_camera_ur10.py
# 终端 B
cd ~/UR10 && source /opt/ros/humble/setup.bash && source ~/colcon_ws/install/setup.bash
python3 scripts/validate_mecheye_capture.py
```

- 若**仍超时**：先把现象、日志（`~/.ros/log/…`、SDK 输出）、复现命令写进
  `experiments/2026-09-18-相机采集链路不通.md`，**不要**跳过这步硬上标定。
- 若**正常**：把它记进实验记录，然后继续第 4 步。

## 4. 标定流程（按顺序做，每步留数值证据）

1. **布置与基准**
   - 棋盘格固定在台面（平放或倾斜都可，但需同一帧内可见、不反光、不被相机/夹爪自遮挡）。
   - 用尺量方格实长（验证打印比例：应 ≈ `6 mm`，记录实测值与量具）。
2. **采集**
   - 复用现有脚本：`python3 scripts/collect_handeye_sample.py …`（看 `--help` 取参数）。
   - 采 **≥20 个样本**，姿态**分布要散**：平移至少覆盖 3 个位置、朝向至少 3 个不同方向
     （只有平移或只有旋转会退化，手眼解会不稳）。
   - 每个样本落盘到 `outputs/handeye/samples/<id>/`：`image.png` + `sample.json`
     ——**务必同时保存原始点云/中间量**（09-17 只存摘要，导致无法离线复核，是那次最大的证据缺口）。
3. **求解**
   - `python3 scripts/solve_handeye_checkerboard.py …`：Park 解 **+ 与 Horaud（或 Tsai）交叉比对**；
     报设计矩阵条件数、训练残差、留出残差。
   - 留出集固定 **≥5 个样本**，且必须**不参与**求解。
4. **独立验收**
   - 冻结 yaml 之后**再采一组新样本**（完全不参与拟合），报平移/旋转误差；
   - 另外做**固定棋盘格闭环**：同一世界点在多个姿态下的重投影/闭环一致性；
   - 两项都要给数字，不给"看起来对"。
5. **落文档**
   - 全部门限通过 → 写 `docs/`（手眼章节）+ 同步 `docs/00` 与 `HANDOVER.md`
     （注意与并行 agent 的冲突：改前先 `git status` 看有没有别人刚改）。
   - 未通过 → 写 `experiments/`，并把 `valid: false` 与失败数值写进 yaml。
6. **收尾**：`python3 scripts/check_current_docs.py` 必须通过。

## 5. 判据（写进结论，不达标就是 `valid: false`）

| 项目 | 门限 |
|---|---|
| 留出集闭环 平移 | RMS ≤ 3 mm、最大 ≤ 5 mm |
| 留出集闭环 旋转 | RMS ≤ 1°、最大 ≤ 2° |
| 冻结后独立样本 | 平移 ≤ 5 mm、旋转 ≤ 2° |
| 交叉方法差异（Park vs Horaud/Tsai） | 平移 ≤ 1 mm、旋转 ≤ 0.5° |
| 标定板重投影 | RMS ≤ 0.5 px |

## 6. 关键坑（都是本仓库踩过的，别重犯）

1. **单可见侧面推物体中心时，偏移方向由"相机在哪一侧"决定**（凸体只露朝向相机的那个面）。
   旧脚本 `scripts/locate_cube_near_checkerboard.py` 用"远离棋盘格中心"判方向，
   在 2026-09-17 的实测里**差了 50 mm**（可见侧面在 target `x=+0.0528 m`，相机在 `x=+0.3641 m`）。
2. **尺寸先验必须实测验证**：09-17 把"50 mm 标称边长"硬编码进推算，而实测可见跨度只有
   `44.28 mm`，先验本身没被验证过。
3. **原始点云/中间量必须落盘**，只存摘要等于没存。
4. **不要用 `ros2 node list` 判断节点是否启动**：本机实测它返回空，而 `ros2 topic list`
   正常；用 `ros2 topic list` / `ros2 service list` / `ps`。
5. 相机是**单色**（PRO XS 硬件规格），别把 `bgr8` 三通道当彩图。
6. 多网卡环境（有线 + 无线 + tun）：相机 SDK 会抱怨
   "Failed to obtain the IP address of the computer Ethernet port connected to the device"，
   但会按 IP 直连成功——该警告本身不代表故障。

## 7. 顺带要做（同一轮，视觉几何闭环）

标定完成后，用本轮已经做好的新工具做**物块中心测量验收**（这才是第 6 节的实际前置）：

```bash
# 现场：相机已启动、机器人静止，同一帧同时看到棋盘格与物块
python3 scripts/measure_cube_geometry.py --capture \
  --save-cloud outputs/vision/clouds/cube-<tag>.npz \
  --output outputs/vision/cube-measurement-<tag>.json
# 之后可离线复算（不需要相机/机器人）：
python3 scripts/measure_cube_geometry.py --npz outputs/vision/clouds/cube-<tag>.npz
```

- 该工具用**顶面平面 + 最小外接矩形足印 + 参考站立面**算中心，带硬门禁（覆盖率 ≥ 0.85、
  与棋盘格面平行 ≤ 12°、长宽比 ≤ 1.10、点数下限），**不满足就拒识**，
  并且会把"实测边长 ≠ 标称 50 mm"单独报成 `measured_size_prior_mismatch`。
- 它的离线数值门禁已通过 6/6（含"掠射视角只见侧面必须拒识"）：
  `python3 scripts/test_measure_cube_geometry.py` →
  `outputs/vision/measure-cube-offline-selftest-20260918.json`。
- **验收要求**：在**≥3 个重新摆放位置**各测一次，用**独立真值**（钢板尺/卡尺实测，
  或顶面+侧面交叉解算，或落点后的接触点）比对，报告误差分布。
  **不要**再用 2026-09-17 那次"人工目测纠正点"当基准——它与任何单侧面重建都不自洽
  （残差 22.2 mm，见 P0-B 记录）。

## 8. 交付物清单

- `config/handeye_eye_in_hand_<日期>.yaml`：`valid`、方法、训练/留出样本数、各项残差、
  验收门限与结论、`validation_failures`（失败时逐条写数值）。
- `outputs/handeye/samples/<id>/`：图 + JSON + **原始点云/中间量**。
- `outputs/vision/clouds/*.npz` + `cube-measurement-*.json`（多位置验收）。
- `experiments/2026-09-<日期>-眼在手棋盘格重标定.md`：过程、数值、失败也写。
- 若相机链路不通：`experiments/2026-09-18-相机采集链路不通.md`。
- 结束时 `python3 scripts/check_current_docs.py` 通过。

先给我一份"现状核对 + 你打算怎么采（姿态数量与分布）+ 预计风险"的简短计划，
我确认后再开始采样本。

===== PROMPT 结束 =====

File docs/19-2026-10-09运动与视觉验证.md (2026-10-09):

# 2026-10-09 运动与视觉验证

本页记录本次发布的代码修复和现场证据。它不修改 UR10 出厂 DH 参数，也不把相机测量当作外部计量设备的精度认证。上一版 `v2026.09.30` 保留。

## 代码变化

- 监控台冷启动等待真实 HTTP 应答，桥进程提前退出时立即报错，不再依赖固定的两秒等待。
- 自动抓取子进程统一使用系统 NumPy/SciPy，避免本机 `~/.local` NumPy 与系统 SciPy 混用；单独启动的网页监控台不受此环境变量影响。
- 主动视角采点云时，对短暂服务超时做有限重试；超时视角不读取同名旧报告。报告文件带本次采集 ID；多视角合并检查当前采集状态、时间、角度、中心一致性，并允许同一次运行中已稳定的悬停观测参与合并。
- 定量 `movel` 脚本改用可用的 UR 30013 状态流，增加 `--dry-run`、低速/距离限制、机器人状态、关节限位、奇异性及模型自碰撞预检、启动前状态复核和运动后停稳检查。模型不包括全部工作台与线缆；真机运动仍需现场监看。

上述代码通过 Python 编译和 `start_dashboard.sh` shell 语法检查；监控台冷启动、主动视角离线归档及一次低速定量运动曾在本机分别验证。**本次修改后的完整自动抓放流程尚未重新完成真机端到端验收。**

## 2026-10-09 定量运动与棋盘格复核

- 定量移动脚本的一次 `base` 坐标系 Y +100 mm 低速执行，控制器目标/回读终点差 0.140 mm，记录在 [`relative-y-plus-100mm-20261009.json`](../outputs/vision/relative-y-plus-100mm-20261009.json)。这只是控制器内部一致性，不是外部实测误差。
- 另一次由操作者确认的 Y +100 mm 移动，前后各拍两张固定棋盘格。四组原图和相机结果分别见 [`preflight`](../outputs/vision/board-motion-validation-preflight-20261009/result.json)、[`before-repeat`](../outputs/vision/board-motion-validation-repeat-20261009/result.json)、[`after`](../outputs/vision/board-motion-validation-after-yplus100mm-20261009/result.json)、[`after-repeat`](../outputs/vision/board-motion-validation-after-repeat-20261009/result.json)。原图与各 `result.json` 同目录，供重新检测和复算。
- 移动前两张原程序漏检；对图像 ROI `(560,230)–(850,350)` 做 CLAHE 和 3 倍放大后，均检出完整 9×6 内角点。移动后两张直接检出。四次 PnP RMS 为 0.291、0.272、0.317、0.335 px；依据 6 mm 方格求得相机相对棋盘格的位置变化为 `[+6.792, -99.878, -0.880]` mm（棋盘格坐标系），长度 **100.113 mm**。
- 移动前复拍位置差 0.155 mm，移动后复拍差 0.327 mm。100.113 mm 与名义 100 mm 的差值不能解释为机械臂绝对误差 0.113 mm；还存在相机内参、方格实物尺寸、角点/PnP、手眼和姿态变化等误差。
- 用现有 `tool0_from_camera` 手眼旋转和移动后读取的 UR 位姿估算，相机位移在 `base` 中约为 `[-1.247,+100.101,+0.862]` mm，距 +Y 约 **0.868°**，横向分量约 1.516 mm。UR 姿态不是与四张图严格同步记录；两端视觉姿态估计还相差约 0.2°。因此这只是相机位移方向估计，**不能判定机器人 Y 轴本身偏转 0.868°**。

## 后续使用边界

不要据此修改出厂 DH。若要定量判断法兰方向精度，应对每张图同步记录关节角与法兰位姿，扣除相机安装偏置在姿态变化时带来的位移，并在多位置重复。现有固定棋盘格适合工作区相对验证；要认证绝对毫米级精度仍需独立计量基准。

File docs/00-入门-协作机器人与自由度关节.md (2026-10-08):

# 00 · 入门基础：协作机器人 / 自由度与关节

> 这是本仓库 `docs/` 里"使用说明"之外补上的**基础概念教程**。
> 目的是先讲清楚"UR10 是什么、机械臂怎么转"，再去读 `01-硬件与网络.md`、`03-机械臂控制.md` 等操作文档。
> 如果你已经能上手操作，这篇可以当速查。

---

## 1. UR10 是什么

UR10 是丹麦优傲机器人（Universal Robots，下称 **UR**）公司的**六轴协作机械臂**（cobot）。
UR 的经典产品线按负载/尺寸从小到大为 **UR3、UR5、UR10、UR16**；后来升级为 **e 系列**
（UR3e / UR5e / UR10e / UR16e）和更晚的 UR20 / UR30。

**UR10 的核心规格（CB3 代，本仓库设备）**：

| 参数 | 数值 |
|---|---|
| 轴数 / 自由度 | 6 轴（6 自由度），与人手臂类似 |
| 有效负载 | 10 kg |
| 工作半径 | 1300 mm |
| 重复定位精度 | ±0.05 mm（±0.10 mm 标称范围中有差异，以官方数据表为准） |
| 自重 | 约 33.5 kg |
| 控制柜 | CB3（本仓库是 CB3 代，软件 PolyScope URSoftware 3.15.8） |
| 协作特性 | 力/力矩受限、碰撞检测、安全区域可配置，可无护栏与人协同 |

本仓库实测的 UR10 序列号 `2022300602`，即属于 CB3 代。注意 **UR10 与 UR10e 不是同一款**
——e 系列是后一代（更高精度、力传感器增强、新的示教器），本仓库的配置与参数按 CB3 的 UR10 记。

在线数据表与介绍（取回页面时标注为不确定的均以官方最新为准）：

- UR 官网产品页：https://www.universal-robots.com/products/ur10-robot/
- UR DH 参数官方文章：https://www.universal-robots.com/articles/ur/application-installation/dh-parameters-for-calculations-of-kinematics-and-dynamics/

> ⚠️ **本仓库的操作文档（`docs/01`）记录的 IP、端口、标定结论都是针对"这台" UR10 的实测值**，
> 先读通本篇基础，再对照实测，不要拿通用资料里的数值覆盖本机标定结果。

---

## 2. 协作机器人（cobot）是什么

传统工业机器人大多要求装进 **安全围栏/安全光栅**，人机隔离。协作机器人（collaborative robot）
重点解决"让人和机器人**共享工作空间**"：

- **负载与速度可配置受限**：因为力/力矩一般不大，撞到人能伤害有限；
- **碰撞检测**：关节力矩超限或检测到外力时触发保护性停止（Protective Stop）；
- **力受限模式 / 拖动示教（手动牵引）**：可双手拖着机械臂走出轨迹，记录路径再回放；
- **安全区域（Safety Plane）**：在示教器上画禁区，进入即停。

UR 属于典型协作机器人。但协作不等于"绝对安全"——装了重负载、高速、尖锐工具后同样要隔离评估。

> 🖼 **协作机器人示意**（此图是 Yamaha 展品，仅用于示意"能在人附近作业的 cobot"，不是本仓库的
> UR10，型号以 `docs/01` 实测为准）：
>
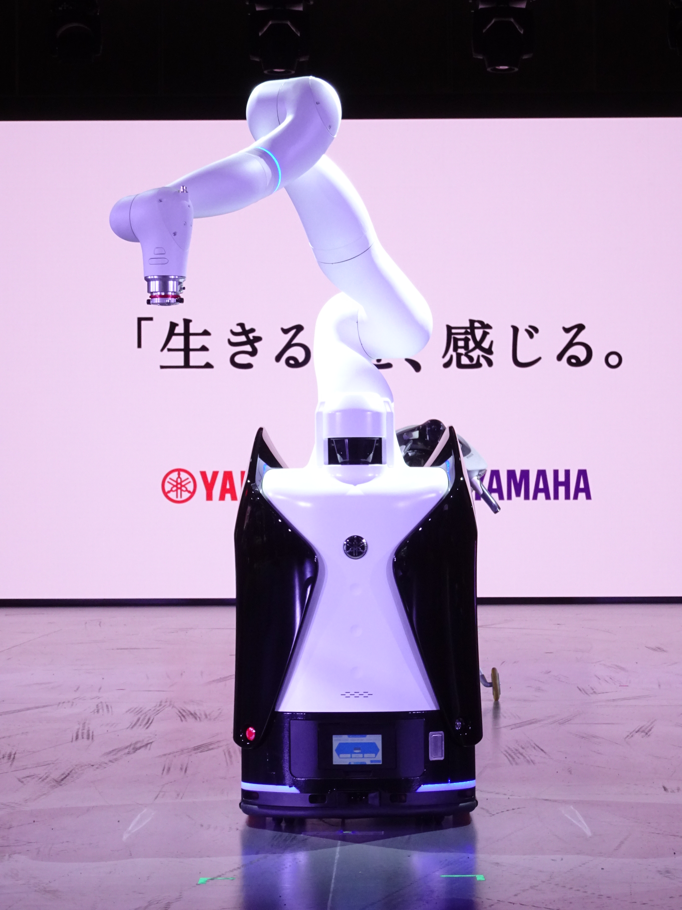
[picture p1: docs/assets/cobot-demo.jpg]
协作机器人示意图
> 
> 图源：[Wikimedia · File:Japan-Mobility-Show-2023-RuinDig 586.jpg](https://commons.wikimedia.org/wiki/File:Japan-Mobility-Show-2023-RuinDig_586.jpg)，
> 作者 RuinDig/Yuki Uchida，授权 **CC BY 4.0**。

本仓库的机器人末端装了 **Robotiq 夹爪 + ATI 力传感器 + 3D 相机**（见 `docs/01`），
重心明显偏置，因此**松刹车/上电前必须先扶住或确认姿态稳定**（`docs/01` 已强调）。

---

## 3. 六轴机械臂：自由度（DoF）

**自由度（Degree of Freedom, DoF）** 指机械臂独立可控的关节数。
六轴机械臂 = 6 个关节，一般用来在三维空间里**任意摆出"位置 + 姿态"**（共 6 个独立量：
3 个平移 + 3 个旋转）。

> 🖼 **6 自由度示意**（三个平移 + 三个旋转，CC BY-SA 4.0，作者 GregorDS）：
>
> 6 自由度示意图
> 图源：[Wikimedia · File:6DOF.svg](https://commons.wikimedia.org/wiki/File:6DOF.svg)，
> 授权 [CC BY-SA 4.0](https://creativecommons.org/licenses/by-sa/4.0/)。UR10 的自由度就是这 6 个
> （沿 x/y/z 移动 + 绕 x/y/z 转动）。

用人来类比：
- 3 自由度（如多数移动扫地机）：只能平面上前后左右转，够不到高，朝向也有限；
- 5 自由度：多数位置能到，但**姿态有约束**，某些朝向到不了；
- **6 自由度（UR10）**：空间中绝大多数点位 + 姿态都能到达，是通用装配/抓放/打磨的最低标准；
- 7 自由度（如部分高级协作臂）：冗余，可在固定末端位姿下改变"肘部"位置（避障/人体学）。

UR10 的 6 个关节从底盘到末端依次习惯命名为：

| 关节 | 名称 / 位置 | 大致对应人的部位 | 在仓库里的称呼 |
|---|---|---|---|
| Joint 1（J1） | 底座 / 基座旋转 | 腰 | 底座旋转 |
| Joint 2（J2） | 肩关节 | 肩 | 上臂摆动（大臂） |
| Joint 3（J3） | 肘关节 | 肘 | 前臂摆动 |
| Joint 4（J4） | 腕 1（沿小臂轴向旋转） | 腕部旋转 | 腕关节一组 |
| Joint 5（J5） | 腕 2（俯仰） | 腕部俯仰 | 腕关节一组 |
| Joint 6（J6） | 腕 3（末端工具旋转） | 手旋转 | 腕关节一组 |

**J4–J6 三个关节交于（近似同一个点的）"球腕"（spherical wrist）**，这是 UR 系列的典型结构，
正/逆运动学有现成解析解（见 `00-入门-运动学`）。

---

## 4. 关节运动范围与工作空间（workspace）

- **关节运动范围（Joint limits）**：UR10 每轴有转角限制（例如 J1 ±360°、J2 -360°~+360° 等，
  以官方数据表为准）。不要只按 `[-180°,180°)` 假设——本仓库 `docs/01` 实测到
  **控制器报告的关节角是连续角**，`J4 = -233.547°` 也是合法值。做限位/插值时用控制器原始值，
  **不要先归一化**（归一化会让插值路径反向绕行）。
- **工作空间（workspace）**：UR10 可达半径约 1.3 m，近似一个"球冠"（球缺）形状，
  但不是完整球——受关节限制、奇异位形、自碰撞约束，底座附近和身体正下方常常受限。
- **奇异位形（singularity）**：某些姿态下机械臂丧失某些方向的自由度（如大臂完全伸直、
  球腕对齐），表现为"末端想直线走但关节突然急剧加速"。见 `00-入门-运动学`。

---

## 5. 关节空间 vs 笛卡尔空间（两条"命令语言"）

这是理解所有机械臂操作的核心分界。`docs/01` 第 8 节已给出示教器上的两种点动方式，
这里补理论：

### 5.1 关节空间（Joint Space）
用 **6 个关节角**（`q = [q1, q2, q3, q4, q5, q6]`）描述机械臂状态。
- 优点：定义简单，不会"跑出可到范围"；接近关节限位、奇异位形的行为可控。
- 缺点：末端具体走到哪、朝向怎么变，**不直观**（要脑内"想一想"）。

UR 里关节角单位常用**弧度**，但示教器/URScript 也常用度。本仓库 `read_ur_state.py`
读 `q_actual`（关节角）、`tool_vector_actual`（TCP 位姿），详见 `docs/01`。

### 5.2 笛卡尔空间（Cartesian Space / Pose Space）
用 **末端工具的中心点（TCP）的位置 + 姿态**描述机械臂状态（见 `00-入门-坐标系与位姿`）。
- 优点：直观——"TCP 走到 (x,y,z)，朝向是斜向下 45°"。
- 缺点：机械臂内部其实没有"凭空" 6 个笛卡尔马达，必须由控制器**解运动学**（IK，见 `00-入门-运动学`）
  反推出 6 个关节角才能动；遇到奇异位形/无解姿态会失败。

> 一句话记忆：
> **关节空间 = 拧哪几个马达；笛卡尔空间 = TCP 在三维世界里走到哪、朝哪。**
> 示教器上"Move/点动笛卡尔"和本仓库的控制脚本本质都是：给目标位姿 → IK 解出关节角 → 伺服执行。

---

## 6. 一台完整的 UR 机械臂由什么组成

| 组成 | 作用 | 本仓库对应 |
|---|---|---|
| **机械臂本体（arm）** | 6 个关节马达 + 减速器 + 连杆 + 末端法兰 | UR10 本体 |
| **末端法兰（flange）** | 装工具的安装法兰，即 `flange` 坐标 | 法兰 → ATI 力传感器 |
| **控制柜（control box, CB3）** | 运行 PolyScope，执行程序、做运动学计算、跑安全层 | CB3 |
| **示教器（teach pendant / Polyscope 触摸屏）** | 人机界面：编程、点动、看状态、设置系统 | 随柜触摸屏 |
| 末端执行器（end effector） | 夹爪、吸盘等"手" | Robotiq 2F 夹爪 |
| 外围传感器 | 力/力矩、视觉 | ATI Net F/T、Mech-Eye PRO XS |

本仓库的"电脑"并不是机械臂的一部分，而是通过 IP 网络驱动它（见 `docs/01`、`docs/02`）。

---

## 7. 一套入门必看的知识链路

建议读文档顺序：

1. 本篇（协作机器人与自由度/关节）→ 知道"几个轴、怎么转"；
2. `00-入门-坐标系与位姿` → 知道"TCP/坐标系/姿态怎么表示"；
3. `00-入门-运动学` → 知道"位置和姿态怎么换算成关节角"；
4. `00-入门-TCP与末端与负载` → 知道"装了工具后中心点变成什么、重心在哪"；
5. `00-入门-PolyScope与URScript` → 知道"程序上怎么让机械臂动"；
6. 再回头读仓库 `docs/01`（本机实测网络/端口/标定）、`docs/03`（机械臂控制）。

---

## 8. 参考与进一步阅读

- UR 官网 UR10 产品页：https://www.universal-robots.com/products/ur10-robot/
- UR 官方协作安全介绍与安全手册：https://www.universal-robots.com/articles/safety-security/
- UR 官方 DH 参数：https://www.universal-robots.com/articles/ur/application-installation/dh-parameters-for-calculations-of-kinematics-and-dynamics/
- UR Academy 免费课程（中文入口）：https://academy.universal-robots.com/cn/

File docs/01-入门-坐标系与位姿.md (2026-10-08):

# 01 · 入门基础：坐标系与位姿

> 读这篇之前先看 `00-入门-协作机器人与自由度关节`。
> 这一篇讲清"位置 (position)"和"姿态 (orientation / pose)"在 UR 里是怎么表示的，
> 以及 base / flange / tool0 / TCP / 工具坐标系这些名词到底指什么。

---

## 1. 为什么机械臂需要"坐标系"

机械臂的 6 个关节角只能告诉我们**马达转到哪**，但要让机器人"把夹爪送到桌子上那杯水的正上方、
朝向向下"，我们需要建立一个**三维参考系**来描述空间位置和朝向。这个参考系就是坐标系（frame）。

UR 把空间里每一个"有名字、有原点、有朝向"的三维直角坐标系叫一个 **frame**。
`x` 向前、`y` 向左、`z` 向上（都是右手系，`x × y = z`）。

---

## 2. 几个关键 frame（UR 官方定义）

下面这张表是 UR ROS2 驱动文档（`ur_description`）中定义的 KDL/URDF 运动链，以及它们和
示教器（Polyscope）显示值的关系：

```
base_link
 ├ base            ← 与 base_link 同位置，但绕 Z 轴旋转 180°，与示教器 "Base" 参照一致
 └ base_link_inertia   （仅惯性/网格挂载用，运动学上等同 base）
    └ shoulder_link
       └ upper_arm_link
          └ forearm_link
             └ wrist_1_link
                └ wrist_2_link
                   └ wrist_3_link
                      └ flange
                      └ tool0
```

| frame 名 | 位置/含义 | 重要提示 |
|---|---|---|
| **base / base_link** | 底座坐标系，"世界"的锚点 | 示教器把某个参照设为 **Base** 时，读到的位姿就是相对 base |
| **flange** | 末端法兰（装工具的那个圆盘）中心 | 给自定义工具/ttool 挂载用；也是"机械臂摆出工具0位姿"的参考 |
| **tool0** | 正运动学算出的"工具坐标系"（工具全 0 配置时的 TCP） | 当系统工具设为"全 0"时，`tool0` ≈ 示教器显示的 TCP |
| **base_link** | 运动链根节点（遵循 REP-103：全零关节配置时臂朝向为 +X） | 与 base 同原点、差 180°，**做 TF 对比示教器数值时不能混用** |

> ⚠️ 重要差异（UR 官方 ROS2 文档明确提醒）：
> ROS/TF 里常用 `base_link`，但**示教器上读的位姿参照是 `base`**（绕 Z 轴转 180°）。
> 拿 ROS 里的 `tool0`-w.r.t-`base_link` 去和示教器"Base 参照 + 全 0 工具"的读数直接对，
> 会差一个 180° 方向的偏置。本仓库 `docs/01` 里"TCP 位姿读数要与示教器对照"时，用的就是
> 示教器自己的 `base` 约定。

---

## 3. 位置（Position）与姿态（Orientation / Pose）

一个"位姿"（pose）= **位置 + 姿态**，共 6 个独立量，对应 6 自由度。

### 3.1 位置：三个平移量
`(x, y, z)`，单位米，相对某个参照 frame 的原点。

### 3.2 姿态：三种常见表示法

| 表示法 | 内容 | 特点 / 在 UR 的使用 |
|---|---|---|
| **欧拉角 RPY（roll/pitch/yaw）** | 绕 X/Y/Z 依次转 `(rx, ry, rz)` | 直观；但**顺序敏感**、有万向节锁（gimbal lock）。UR 示教器状态里常见 RPY（单位弧度） |
| **旋转矩阵 R** | 3×3 方向余弦矩阵 | 适合做数学运算，不直观 |
| **四元数（quaternion）** | `(qx, qy, qz, qw)` | 无万向节锁、便于插值，是 ROS `geometry_msgs/Quaternion` 的格式 |

> 🖼 **欧拉角示意**（α-β-γ，CC BY 3.0，作者 Lionel Brits）——同一个姿态用连续三次旋转表示，
> 旋转**顺序**不同结果就不同，这正是 3.3 要强调的点：
>
> 欧拉角示意图
> 图源：[Wikimedia · File:Eulerangles.svg](https://commons.wikimedia.org/wiki/File:Eulerangles.svg)，
> 授权 [CC BY 3.0](https://creativecommons.org/licenses/by/3.0/)。

UR 的 URScript 里 `p[x, y, z, rx, ry, rz]` 就是"位置 + RPY"。本仓库 `read_ur_state.py`
读到的 `tool_vector_actual` 即这种 **TCP 位姿矢量**（位置 + 旋转矢量，见 `docs/01`）。

### 3.3 姿态为什么"顺序"这么重要
同一个末端姿态可以用**无数种**欧拉角组合表示，且**旋转顺序不同结果不同**。
做笛卡尔插值/IK（`00-入门-运动学`）时，务必先约定并统一用哪套约定（UR 用的是内置约定，
一般"先转哪个轴"由系统固定）。

---

## 4. 世界 / 基座 / 工具 / 工件：四种常用参照

做任务时你会反复用到这几类 frame：

1. **世界坐标系（World）**：整个工位的锚，比如桌面原点。
2. **基座坐标系（Base）**：UR 的 `base`，即上一节的底座 frame。UR 示教器里参照如设
   "Base" 就是从底座量位姿。
3. **工具坐标系（TCP / Tool）**：以**夹爪夹持点或工具尖端**为原点。装上 Robotiq、相机、
   笔尖等后，你要把 TCP 定义到真正"干活"的点（见 `00-入门-TCP与末端与负载`）。
4. **工件坐标系（Work Object / Feature）**：以**工件/桌面**为原点，便于对工件编程，
   工件移动时只改这个参照即可。

> 记忆：**同一个物理点，在不同参照下读数不同。**
> 做标定/对比时先问"参考系是谁"。（本仓库 `docs/11-机器人自身标定`、`docs/17-视觉自主抓取验收`
> 里大量"参照/坐标系"的坑，本质都是这个。）

---

## 5. 本仓库里"坐标系/位姿"相关的坑（实测提醒）

1. **TCP 位姿是"当前 TCP 定义"下的位姿**（`tool_vector_actual`），不一定是 `tool0`。
   当前控制器 TCP 是 `tool0`；`docs/11` 标定出笔尖/抓取 TCP 后，同一物理点读数整体改变，
   **历史点位必须先迁移**。（出处：`docs/01`）
2. **示教器 vs ROS 的 base 差 180°**：见第 2 节，别直接拿 `base_link` 读数对示教器。
3. **关节角是连续角**：`J4=-233.547°` 合法，插值/限位用原始值，别归一化。（出处：`docs/01`）
4. **位姿＝位置＋姿态**：读状态只看了 `x,y,z` 没看朝向，搬运/抓取一定偏。定位到"正上方"后还要核对朝向。

---

## 6. 参考

- UR 官方 ROS2 驱动文档 · Robot Frames（base_link/base/tool0/flange 与示教器关系）：
  https://docs.universal-robots.com/Universal_Robots_ROS_Documentation/rolling/doc/ur_description/doc/robot_frames.html
- REP-103 标准单位与坐标系惯例：https://ros.org/reps/rep-0103.html
- REP-199（base/tool0 帧提案）：https://gavanderhoorn.github.io/rep/rep-0199.html

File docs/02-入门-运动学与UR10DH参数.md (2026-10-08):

# 02 · 入门基础：运动学与 UR10 的 DH 参数

> 前置：`00-入门-协作机器人与自由度关节`（关节/笛卡尔空间）与 `01-入门-坐标系与位姿`（frame）。
> 这一篇讲"给定关节角→末端位姿（正运动学）"和"给定末端位姿→关节角（逆运动学）"，
> 以及 UR 官方公布的 **UR10 DH 参数表**。工程上你大多**不需要手算**，但理解了它才看得懂
> 奇异位形、IK 失败、以及本仓库大量标定/规划脚本在忙什么。

---

## 1. 正运动学（Forward Kinematics, FK）

已知 6 个关节角 `q = [q1..q6]`，算出末端（tool0 / TCP）在 base 下的位置与姿态。

- 方法：把每个关节的连杆变换 `T_i` 连乘 → `T_0^6 = T_1(q1)·T_2(q2)···T_6(q6)`。
- 结果**唯一**：给定 6 个角，末端位姿只有一个答案。
- 控制器给示教器显示 TCP/读 `tool_vector_actual`，本质就是 FK。

## 2. 逆运动学（Inverse Kinematics, IK）

反问题：给定末端位姿 **`(x,y,z, 姿态)`**，求出关节角 `q`。

- 结果**不唯一**：同一个末端位姿通常有多组解（肘上/肘下、腕翻转等）。UR 内置解法会挑选
  一组（按当前关节、行程、避免奇异）。
- **可能无解**：目标点超出可达范围、或姿态要求无法满足 → 报错/保护停。
- **接近奇异位形时**：末端要直线走，但某些关节角变化率逼近无穷，机器人会剧烈加速甚至触发
  protective stop（本仓库 `experiments/2026-09-14-ik-servoj-protective-stop.md` 就是在排查
  这类问题）。

> 🖼 **正/逆运动学对比**（CC BY-SA 4.0，作者 Haendy-freak）——左：FK（关节角 → 末端位姿；
> 唯一）；右：IK（末端位姿 → 关节角；多解）：
>
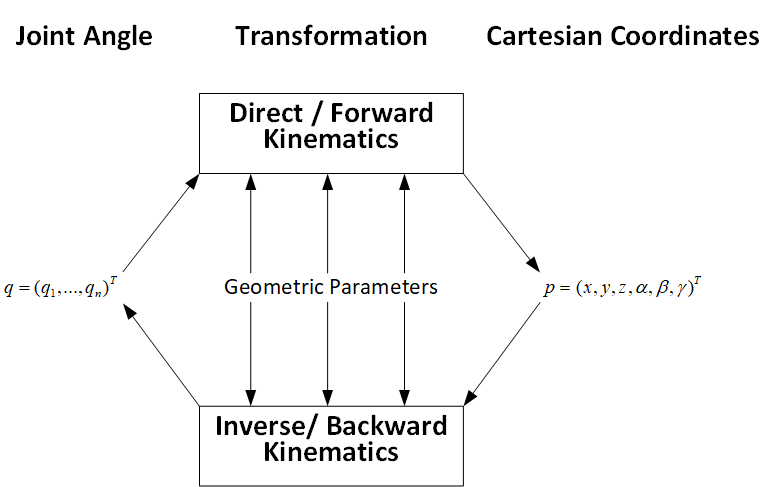
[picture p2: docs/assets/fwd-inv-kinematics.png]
正逆运动学对比
> 
> 图源：[Wikimedia · File:FWDvsINV Kinematics HighResTransp.png](https://commons.wikimedia.org/wiki/File:FWDvsINV_Kinematics_HighResTransp.png)，
> 授权 [CC BY-SA 4.0](https://creativecommons.org/licenses/by-sa/4.0/)。

> 工程结论：**笛卡尔运动不是"拍照就动"，要先当心 IK 是否有解、是否奇异。**
> 这也是本仓库"不执行电脑端流式 IK 真机运动"边界（README）背后的一条基础原理。

---

## 3. UR10（CB3）DH 参数表

UR 官方用 **Denavit–Hartenberg（DH）参数**来描述连杆几何。UR 官方注释：
> "UR 的 `a` 参数 = 维基百科 DH 里的 `r` 参数"

> 🖼 **DH 参数的 `a/d/alpha` 长什么样**（开放授权图，作者 Ethan Tira-Thompson，CC BY-SA 3.0）：
>
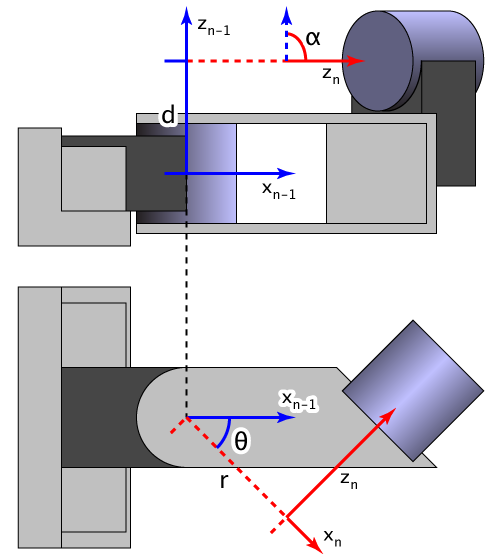
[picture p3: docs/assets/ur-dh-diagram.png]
DH 参数示意图
> 
> 图源：[Wikimedia · File:Sample Denavit-Hartenberg Diagram.png](https://commons.wikimedia.org/wiki/File:Sample_Denavit-Hartenberg_Diagram.png)，
> 授权 [CC BY-SA 3.0](https://creativecommons.org/licenses/by-sa/3.0/)。它展示的是**通用** DH 帧对，
> UR10 各轴代入的是下方表格的参数值。
>
> 在 `docs/06-入门-图片与授权清单.md` 里有更多开放授权/开源教程配图的来源对照。

| 关节 i | `a` [m] | `d` [m] | `alpha` [rad] |
|---|---|---:|---:|---:|
| 1 | 0 | 0.1273 | π/2 |
| 2 | -0.612 | 0 | 0 |
| 3 | -0.5723 | 0 | 0 |
| 4 | 0 | 0.163941 | π/2 |
| 5 | 0 | 0.1157 | -π/2 |
| 6 | 0 | 0.0922 | 0 |

> - `a`：相邻关节轴的公垂线长度（沿 x 方向）
> - `d`：沿 z 方向的偏移
> - `alpha`：绕 x 轴旋转的连杆扭转角
> - 该表是**标准 DH**，且相接关节平行处出现较大数值属正常（官方说明："standard DH 表示平行关节
>   时是奇异/敏感记法，期望出现大数代表小角度调整"）。
> - UR 官方同时给出动力学数据（每根连杆质量、质心、惯量矩阵）。UR 官方文章还说，
>   **惯量矩阵对于 UR3e/UR5e 可忽略，从 UR10 起开始有影响**——这正是本仓库做
>   `docs/11` 负载标定、`docs/12` 重力补偿的物理基础。

来源：官方 DH 文章 https://www.universal-robots.com/articles/ur/application-installation/dh-parameters-for-calculations-of-kinematics-and-dynamics/

> ⚠️ 型号区分就是这表的关键差异：UR10(CB3) 和 UR10e 的 **`a2`/`a3` 不同**（UR10e 为
> `-0.6127` / `-0.57155`，`d1` 也不同）。ROS/URDF 模型和你的 IK 库**必须与机型匹配**，
> 否则算出来的几乎每个位姿都偏。本仓库 `config/ur10_factory_calibration.yaml` 属于**这台**
> UR10 的标定，不要拿 UR10e 的参数覆盖。

---

## 4. 奇异位形（Singularity）简解

当雅可比矩阵（关节速度↔末端速度的映射）**降秩**时，某个方向无法再运动 → 奇异。

UR 常见三种：
1. **臂型奇异（shoulder singularity）**：肩/肘共线；
2. **腕奇异（wrist singularity）**：球腕 J4 与 J6 轴对齐；
3. **肘奇异（elbow singularity）**：肘关节接近伸直。

表现：末端想沿某个方向匀速，但某些关节角速度飙高；控制器保护停或路径突然扭转向。

**规避思路**：规划路径时加中间过渡位姿、避开极限姿态、用关节空间插值而非纯笛卡尔。

---

## 5. 本仓库会遇到运动学的地方

| 位置 | 用途 |
|---|---|
| `docs/01` 正运动学 | 读 `q_actual` → 算 TCP / 与示教器对照 |
| `docs/03` 机械臂控制 | 给目标位姿 → IK 解算（ROS 官方驱动/控制器） |
| `docs/11` 机器人自身标定 | TCP、负载、运动学标定（标定就是反过来求真实 DH/TCP） |
| `docs/12` 力传感器重力补偿 | 用姿态+质量估计力学模型，本质依赖几何与动力学 |
| `experiments/2026-09-14-*` | ik-servoj / protective-stop 排查 |

---

## 6. 进一步阅读

- 官方 DH 文章（含所有机型的表与 DH-Transformation.xlsx）：见上方链接
- DH 参数百科：https://en.wikipedia.org/wiki/Denavit–Hartenberg_parameters
- UR ROS2 `ur_description`（URDF/DH 实现）：https://github.com/UniversalRobots/Universal_Robots_ROS_Driver

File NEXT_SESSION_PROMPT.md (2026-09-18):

# 下一个会话的提示词（DSH）

> 用途：开新对话时把下面代码块整段粘贴。**刻意写短** —— 提示词本身也占上下文，
> 细节都在仓库文件里，让新会话按需去读。

```text
继续 UR10 机械臂工程实践课程，本轮做第 1–6 节（第 7、8 节已决定延后，不采购硬件）。

第一步先读这三个文件（不要假设旧文档里的"已完成"仍然有效）：
1. ~/UR10/HANDOVER.md 顶部「0A. 最新接手状态」—— 唯一权威状态
2. ~/UR10/experiments/2026-09-18-八节课实施计划草案.md —— 逐节做法与前置依赖
3. ~/UR10/docs/00-当前可用操作.md —— 当前可执行入口

当前进度：第 1、2 节已完成并真机只读验证；第 3 节入口已有但只跑过 dry-run；
第 4、5、6 节未做，其中第 5 节被两个 P0 阻塞。

先做 HANDOVER 里的 P0-A（力标定的 2 倍质量矛盾：所有拟合收敛到 3.2 kg，
但单姿态 |F|/g 反推是 6.56 kg，相差 2.03 倍且极度可重复）。
只读排查，不动机械臂；查法与判据都写在 HANDOVER 里。

约束：
- 只读优先；任何真机运动前先查 HANDOVER 的「当前严格禁止」
- 结论必须有数值证据：失败写 experiments/，原始 CSV/JSON 写 outputs/，
  只有独立验证通过的稳定结论才进 docs/
- 改完跑 python3 scripts/check_current_docs.py
- 不要开宽泛网络调研、不要开子代理；优先在本地找答案（仓库和 SDK 源码里通常有）
- 读大文件用 offset/limit/grep，不要整读（spill 不覆盖 read 工具）
```

## 为什么这么写

| 设计 | 原因 |
|---|---|
| 只有约 15 行 | 提示词会永久驻留在新会话上下文里，并被之后每一轮重复计费 |
| 先给三个文件路径 | 让新会话**按需定向读**，而不是把内容塞进提示词 |
| 明确"不要假设旧文档已完成" | 这个仓库的历史里"看起来完成了其实失效"是最大坑 |
| 明确禁止宽泛调研/子代理 | 2026-09-18 的成本事故就是 5 个开放式调研子代理造成的 |
| 直接点名 P0-A | 避免新会话从头盘点、重复劳动 |

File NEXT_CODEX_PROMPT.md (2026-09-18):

# 给下一个 Codex 的接手提示词

你接手的是 `/home/jx/UR10` 的 UR10 CB3 + Robotiq 夹爪 + ATI Net F/T + Mech-Eye PRO XS 项目。

第一步必须阅读：

1. `HANDOVER.md`，尤其是顶部 `0A. 最新接手状态`；
2. `docs/14-待办与已知问题.md`；
3. `docs/12-力传感器重力补偿.md`；
4. `docs/09-MechEye相机接入清单.md`；
5. `experiments/2026-09-16-官方ROS2轨迹控制接入与未完成门禁.md`。

不要假设旧文档中的“已完成”仍然代表当前可用，当前状态以 `HANDOVER.md` 顶部为准。

## 已知硬件

- 电脑：Ubuntu 22.04、ROS 2 Humble，用户 `jx`。
- UR10 CB3：`192.168.1.3`，URSoftware `3.15.8.106339`。
- ATI Net F/T：`192.168.1.2`，RDT UDP `49152`，只能有一个消费者。
- Mech-Eye PRO XS：`192.168.1.33`，SDK 2.5.0。
- 夹爪：机器人 `192.168.1.3:63352`，电脑直控 Robotiq ASCII。

## 当前禁止事项

- 不要执行 `scripts/test_ik_move.py --execute`。此前 2 mm 流式 IK 真机试验触发 `C153A0` 保护停。
- 不要使用重力补偿话题做力控、碰撞停止或抓取判断。旧模型独立验证失败，配置已标记 `valid: false`。
- 只使用 `/ft_sensor/wrench_raw` 做新的重力数据采集。
- 不要运行 `scripts/ur_pick_place_full.py`。该脚本仍使用未验证的
  `8.0 kg / [-0.03,0.03,-0.06]` 负载估计值。
- 不要把控制器当前回读的 `3.5 kg / [0,0,0.1] m` 当成独立测量结果。
- 不要把 `/mechmind/color_image` 当成真彩色。PRO XS 的 2D 传感器是单色（硬件规格，
  官方规格表 `2D image color: Monochrome`，型号表无 `C` 后缀彩色版本），实测 bgr8
  三通道完全相同、纹理点云 RGB 也完全相同，因为 SDK 的 `getColorImage()` 在
  Monochrome 时按 `Blue = Gray, Green = Gray, Red = Gray` 复制。这不是待修复的故障，
  不要为“恢复彩色”排查参数或链路。证据见 `outputs/camera/model-identification-20260918.json`。

## 已验证工具

```bash
cd ~/UR10
python3 scripts/diagnose.py
python3 scripts/verify_ur_payload.py
python3 scripts/monitor_ur_safety.py --duration 3
python3 scripts/validate_mecheye_capture.py
```

## 下一步任务

当前主目标已经改为手眼标定。重力补偿暂停，其数据索引在
`archives/ft_gravity_20260916/README.md`，不得删除或把任何候选改成 `valid: true`。

任何新方案实施前，必须先调研行业常用方法和官方推荐做法，优先查 UR/ATI/ROS 2
官方版本化文档及原始论文/实现，记录来源、适用条件和与本机 CB3 3.15.8 的差异，
然后再写代码或上真机。

先现场确认相机安装类型和标定板型号：相机随末端运动用 eye-in-hand，固定外置用
eye-to-hand。先核对 Mech-Eye SDK 2.5.0/Mech-Vision 官方标定板检测能力，再决定
使用官方标准标定还是 easy_handeye2 + 独立目标检测。初期只用示教器手动采样，
至少 15 个有效姿态，不自动运动。结果必须做留出姿态和已知空间点独立验收。

已知标定板格子边长为 `0.6 cm = 0.006 m`；仍需现场确认图案类型、横纵内角点/
圆心数量，不能用方格数量代替棋盘格内角点数量。

建立含夹爪和偏心相机的碰撞模型后，才可在用户监护下进行单段低速真机试验；
不得直接完整回放。自动采集后的重力模型仍必须用未参与拟合的姿态独立验收。

所有结论必须有数值证据。失败实验写到 `experiments/`，原始 CSV/JSON 写到 `outputs/`，只有独立验证通过的结论写入 `docs/`。本轮不需要推送 GitHub，先在本地完成并报告：做了什么、证据是什么、下一步是什么。

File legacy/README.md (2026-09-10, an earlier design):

# legacy —— 已废弃的"示教器 socket 方案"（留档）

这里的代码**不要用于新项目**，保留是为了记录踩过的坑和演进过程。

## 旧方案是怎么设计的

```
  电脑                                              UR 示教器
┌──────────────────────┐                      ┌────────────────────────┐
│ ur_pick_place_*.py   │  ① 机械臂运动        │ 通用执行器程序          │
│  ├ 30002 发 movel ───┼─────────────────────▶│  (读命令→rq_set_pos)   │
│  └ 监听 30010 ◀──────┼──② 夹爪执行器连入────│  socket_open(30010)    │
│     发 grip/release ─┼─────────────────────▶│  rq_set_pos(255/0)     │
└──────────────────────┘                      └────────────────────────┘
```

文件对应关系：

| 文件 | 作用 |
|---|---|
| `ur_pick_place.py` / `_cycle.py` | 早期版本：电脑起 30010 服务器，示教器作为客户端连入 |
| `ur_pick_place_drive.py` / `_hybrid.py` | 驱动版：30002 管臂 + 30010 管夹爪混合 |
| `ur_gripper_server.py` / `socket_test_server.py` / `ur_socket_server.py` | 各种测试服务器（诊断 socket 通不通） |
| `pickplace_observer.py` | 观察示教器程序有没有真的在抓放 |
| `pendant_*.urscript` | 贴在示教器上的程序（通用执行器、夹爪服务器、抓放循环） |
| `演示操作手册.md` | 当时的操作手册 |

## 为什么放弃

1. **`rq_activate()` 死锁** —— 它的等待循环 `while(ACT!=0 or STA!=0)` 在夹爪本来就
   `ACT=1` 时永远出不去。程序卡死，表现为"30010 能看到机器人连入，但发命令永远没回执、
   连接也不断开"。详见 [`../docs/04-夹爪控制.md`](../docs/04-夹爪控制.md)。
2. **URCap 往程序里塞 76KB 代码** —— 安装节点生成的 `def rq_*` 函数库、真空检测线程等，
   手工粘贴极易把残留代码一起带进去。
3. **Script 节点的 `cachedContents` 缓存** —— `.urp` 里存着一份脚本缓存，
   你更新了 `.script` 文件，程序跑的却还是旧缓存。（见 [`../docs/07`](../docs/07-机器人内部访问.md)）
4. **每次改代码都要重播程序**，socket 只能 open 一次，迭代极慢（改一行等一分钟）。
5. **故障点翻倍** —— 网络、示教器状态、URCap 干扰、socket 时序，任何一环都能让你白忙半天。

## 新方案（本仓库正文）

```
  电脑                                    机器人
┌────────────────────┐                ┌──────────────────┐
│ ur_arm.py ─────────┼── 30002 ──────▶│ URControl        │→ 机械臂
│ rq_gripper.py ─────┼── 63352 ──────▶│ drivergripper    │→ 夹爪
└────────────────────┘                └──────────────────┘
       示教器全程不参与
```

- 夹爪：电脑**直连**机器人上的 `63352`（Robotiq 守护进程，IPv6 通配监听，对局域网开放）；
- 机械臂：ROS 话题 `/ur_link/urscript` → 30002；
- 改代码**不用重播程序**，迭代以秒计。

见 [`../docs/04-夹爪控制.md`](../docs/04-夹爪控制.md) 与 [`../docs/05-完整抓放.md`](../docs/05-完整抓放.md)。

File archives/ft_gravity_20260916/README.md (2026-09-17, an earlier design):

# ATI 重力补偿数据存档（截至 2026-09-16）

本目录是索引，不复制原始数据。原始 CSV/JSON、拟合候选和失败实验均保留在仓库
原路径，并已在提交 `4aa8030` 首次完整归档。校验值见同目录 `SHA256SUMS`。

## 当前结论

- 所有 `config/ft_gravity_calibration*.yaml` 均为实验候选或历史配置，当前没有
  通过最终独立验收的模型；不得用于力控、碰撞停止或抓取判断。
- 新采集和以后复算只使用 `/ft_sensor/wrench_raw`，ATI 硬件 Bias 应保持六轴全零。
- 示教播放最终数据共 12 组、每组 5 个窗口；第 11 组由操作者确认是在运动中
  误采，必须排除。使用组 `{1..10,12}` 拟合时，设计矩阵条件数 `8.207`，但力
  RMS `4.208 N`、最大残差 `15.411 N`，仍失败。
- 朝下候选曾在 3 个独立姿态得到力/力矩 RMS `0.643606 N / 0.055344 N·m`，
  随后新姿态反例力 RMS `1.565931 N`，已撤销。
- 全范围鲁棒候选曾在 4 个独立姿态得到 `0.374993 N / 0.049220 N·m`，随后
  在线静态反例为 `2.000 N / 0.110 N·m`，已撤销。

## 数据分组

### 开机基线

- `outputs/ft_baseline/baseline-20260914-162630.json`
- `outputs/ft_baseline/baseline-20260915-pre-restart.json`
- `outputs/ft_baseline/baseline-20260915-post-restart.json`

### 手动训练与验证原始数据

- `outputs/ft_calibration/downward-20260915.csv`
- `outputs/ft_calibration/downward-validation-20260915.csv`
- `outputs/ft_calibration/fullrange-20260915.csv`
- `outputs/ft_calibration/fullrange-robust-validation-20260915.csv`
- `outputs/ft_calibration/repeat12-20260915.csv`
- `outputs/ft_calibration/repeat12-cable-loose-20260915.csv`
- 同目录 JSON 是对应诊断或验证摘要。

### 示教播放重复采样

- 主数据：`outputs/ft_repeats/pendant-playback-20260916-final.csv`
- 元数据：`outputs/ft_repeats/pendant-playback-20260916-final.json`
- `retry`、无后缀版本保留为采集器调试和中断证据，不应与主数据直接拼接。
- `planned-waypoints-20260916.*` 是未完成的被动计划点采集，不是完整训练集。

### 候选模型

- `config/ft_gravity_calibration.downward-20260915.yaml`
- `config/ft_gravity_calibration.fullrange-20260915.yaml`
- `config/ft_gravity_calibration.fullrange-robust-20260915.yaml`
- `config/ft_gravity_calibration.manual.yaml`
- `config/ft_gravity_calibration.manual.round2.yaml`

以上全部保持 `valid: false`。以后复算时应新建文件，不覆盖这些历史候选。

## 关键实验说明

- `experiments/2026-09-11-重力补偿标定与失败验收.md`
- `experiments/2026-09-15-朝下工作区重力补偿独立验收.md`
- `experiments/2026-09-15-全范围鲁棒候选独立验收.md`
- `experiments/2026-09-16-示教播放第11组运动中采集排除.md`
- `experiments/2026-09-16-示教播放静态组拟合失败.md`

## 恢复使用前的最低条件

重新处理时必须保留训练/验证隔离、线缆状态、逐姿态残差和离群点清单。模型需要在
未参与拟合与模型选择的多个姿态上通过预先声明的门限，才允许把 `valid` 改为
`true`。当前项目主目标已切换为手眼标定，重力补偿工作暂停但数据完整保留。

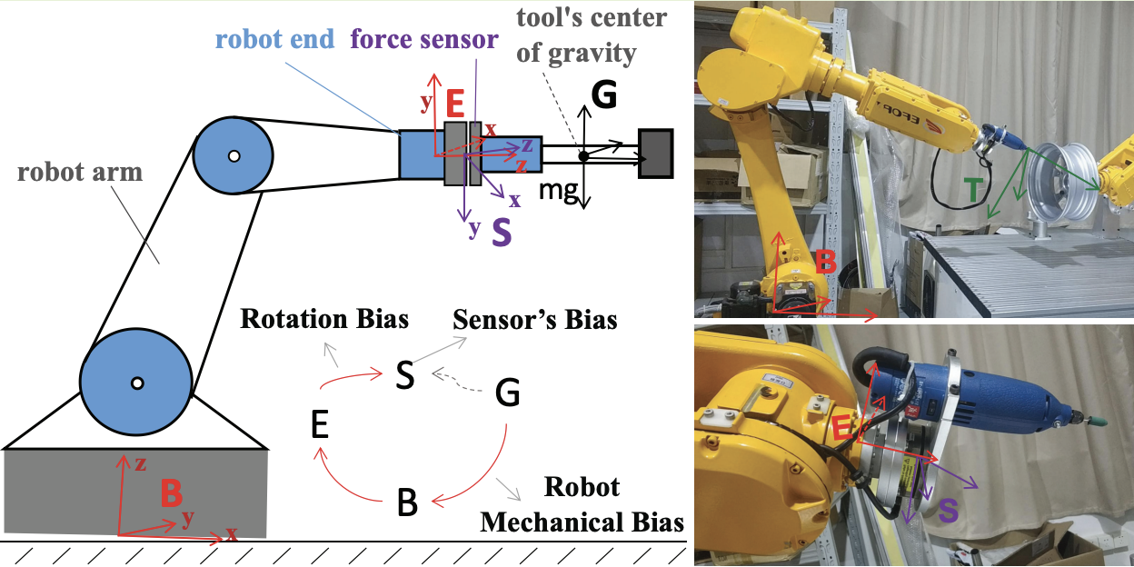
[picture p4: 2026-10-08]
docs/assets/ft_gravity_model.png

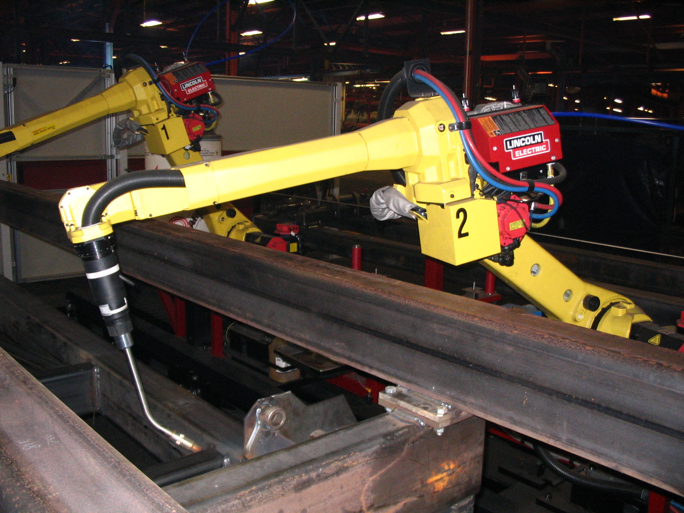
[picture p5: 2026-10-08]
docs/assets/fanuc-robot.jpg

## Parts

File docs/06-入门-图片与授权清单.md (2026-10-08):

# 06 · 入门：图片与开放授权来源清单

> 目的：给本套入门/标定文档配图，并**一份文件交代每张图的来源与授权**，方便合入仓库后
> 维护可追溯性。规则：只列**开放授权**（CC / 公有领域 / MIT 等）或**明确可引用**的来源；
> 商用量产产品照（例如优傲官网照片）默认**受版权保护**，不在仓库内热链或复制。

---

## 0. 你能怎么用这些图

| 方式 | 说明 | 何时用 |
|---|---|---|
| **热链接（hotlink）** | 文档里直接写 `<img src="...">` / `![](url)`，在线渲染 | 图源 URL 稳定、授权允许（Commons 等） |
| **下载放入仓库 `docs/assets/`** | 用 `git`/curl 下载到本地再引用 | 想离线可用、控制体积、规避外链失效 |

> **我在本套文档里用了"热链接"**（见第 1 节）。渲染差异说明：
> - 在 **GitHub 网页 / 浏览器**打开：能显示（只要联网）；
> - 在 **VSCode / Typora 等本地编辑器**预览：可能默认屏蔽远程图片而不显示。
> 如果你要**本机/离线也显示**，运行 `docs/scripts/fetch_images.ps1`（联网环境）把它们下载到
> `docs/assets/`，再把对应 `![](https://...)` 改成 `![](assets/<文件名>)` 即可。

> ⚠️ 我在当前沙箱环境里**拉取 Wikimedia 图片被限流（429/400）**，所以未能替你写入本地二进制；
> 但上面脚本里的 URL 是经 Commons API 核实过的准确直链。

---

## 1. 已内嵌（热链接）的授权图

| 主题 | 图 | 直链（去参） | 授权 |
|---|---|---|---|
| DH 参数 / 运动学（`02-入门-运动学`） | `Sample Denavit-Hartenberg Diagram.png`（Ethan Tira-Thompson 自绘） | `https://upload.wikimedia.org/wikipedia/commons/3/3f/Sample_Denavit-Hartenberg_Diagram.png` | **CC BY-SA 3.0**（`Ejtttje`/Ethan Tira-Thompson） |
| 机械臂 3D 模型（`05-入门-教程汇总`） | `Robot arm model 1.png`（NeD80） | `https://upload.wikimedia.org/wikipedia/commons/9/9b/Robot_arm_model_1.png` | **Public Domain** |
| 正/逆运动学对比（`02`） | `FWDvsINV Kinematics HighResTransp.png`（Haendy-freak） | `https://upload.wikimedia.org/wikipedia/commons/f/f4/FWDvsINV_Kinematics_HighResTransp.png` | **CC BY-SA 4.0** |
| 协作机器人（`00-入门-协作机器人`） | `Japan-Mobility-Show-2023-RuinDig 586.jpg`（RuinDig/Yuki Uchida 摄） | `https://upload.wikimedia.org/wikipedia/commons/b/ba/Japan-Mobility-Show-2023-RuinDig_586.jpg` | **CC BY 4.0**（Yamaha 展品，仅作 cobot 示意） |
| 6 自由度示意（`00`） | `6DOF.svg`（GregorDS） | `https://upload.wikimedia.org/wikipedia/commons/2/2a/6DOF.svg` | **CC BY-SA 4.0** |
| 六轴关节机械臂（`04`） | `FANUC welding robot reaching.jpg`（Phasmatisnox 摄） | `https://upload.wikimedia.org/wikipedia/commons/e/e4/FANUC_welding_robot_reaching.jpg` | **CC BY 3.0**（FANUC 焊接机器人，非 UR10） |
| 欧拉角（`01-入门-坐标系与位姿`） | `Eulerangles.svg`（Lionel Brits） | `https://upload.wikimedia.org/wikipedia/commons/a/a1/Eulerangles.svg` | **CC BY 3.0** |
| 质心/重心（`12-入门标定-负载重心`） | `Center of mass two bodies.svg`（Adiel lo / Mekala Harika） | `https://upload.wikimedia.org/wikipedia/commons/b/bc/Center_of_mass_two_bodies.svg` | **CC BY-SA 4.0** |
| 相机投影 / PnP（`14-入门标定-相机内参`） | `Pinhole-camera.svg`（`en:User:DrBob` 原图，`Pbroks13` 重绘） | `https://upload.wikimedia.org/wikipedia/commons/3/3b/Pinhole-camera.svg` | **Public Domain（公有领域）** |
| 末端执行器（`03-入门-TCP`） | `Shadow Hand Bulb large Alpha.png`（Richard Greenhill / Hugo Elias 摄） | `https://upload.wikimedia.org/wikipedia/commons/f/f4/Shadow_Hand_Bulb_large_Alpha.png` | **CC BY-SA 3.0**（Shadow Robot 灵巧手） |
| TCP 触测（`11-入门标定-TCP`） | `9.12.17 Coordinate measuring machine.png`（Vulture19 摄） | `https://upload.wikimedia.org/wikipedia/commons/b/bf/9.12.17_Coordinate_measuring_machine.png` | **CC BY-SA 3.0**（CMM 三坐标测量机，触测示意） |

各自的出处/授权详情：
- DH：https://commons.wikimedia.org/wiki/File:Sample_Denavit-Hartenberg_Diagram.png （CC BY-SA 3.0）
- 机械臂模型：https://commons.wikimedia.org/wiki/File:Robot_arm_model_1.png （公有领域）
- 正逆运动学对比：https://commons.wikimedia.org/wiki/File:FWDvsINV_Kinematics_HighResTransp.png （CC BY-SA 4.0）
- 协作机器人：https://commons.wikimedia.org/wiki/File:Japan-Mobility-Show-2023-RuinDig_586.jpg （CC BY 4.0）
- 6DOF：https://commons.wikimedia.org/wiki/File:6DOF.svg （CC BY-SA 4.0）
- FANUC 机械臂：https://commons.wikimedia.org/wiki/File:FANUC_welding_robot_reaching.jpg （CC BY 3.0）
- 欧拉角：https://commons.wikimedia.org/wiki/File:Eulerangles.svg （CC BY 3.0）
- 针孔相机：https://commons.wikimedia.org/wiki/File:Pinhole-camera.svg （公有领域，无需署名）

---

## 1b. 本地资产图（已下载到 `docs/assets/`，供离线/本地预览）

> 这些从开源教程 README 取得，**供实验室内部学习、非商用**；正文里用相对路径
> `assets/<文件名>` 引用，因此本地/离线也能显示。来源与授权如下（使用请保留出处）：

| 文件 | 内容 | 来源仓库（README 图） |
|---|---|---|
| `ft_gravity_model.png` | 力/力矩重力补偿模型 | `GeneHit/hand_force_calibration` → `modeling.png` |
| `handeye_eye_in_hand.jpg` | eye-in-hand 装法示意 | `RealManRobot/hand_eye_calibration` |
| `handeye_eye_to_hand.png` | eye-to-hand 装法示意 | `RealManRobot/hand_eye_calibration` |
| `handeye_loop_axxb.png` | AX=XB 变换回路（`15`） | `RealManRobot/hand_eye_calibration` |
| `handeye_calib_plate.png` | AX=XB 立体标定板（`10`标定总览） | `pyni/handeye_calibration_with_depth_camera` |
| `calibboard.png` | 棋盘格标定板（可打印，`14`） | `RealManRobot/hand_eye_calibration` |

其中 RealManRobot 的 README 出处：https://github.com/RealManRobot/hand_eye_calibration
GeneHit：https://github.com/GeneHit/hand_force_calibration
pyni：https://github.com/pyni/handeye_calibration_with_depth_camera
（pyni 仓库未含 LICENSE；因属非商用·内部学习用途，按出处引用并保留来源说明。）

> 可再用 `docs/scripts/fetch_images.ps1` 一键重建 `assets/`（含以上 GitHub 图与 Wikimedia 开放授权图）。

---

## 2. 其余主题的开放教程配图来源（建议自行取图后本地嵌入）

> 这些是"包含合适示意图的**开放教程页面**"。图中可能仍带作者版权，**合入前请点开页面核对
> 每张图的具体授权**；稳妥做法是只引用页面、或自行重绘。我无法在此沙箱里核实每张图的授权和
> 直链是否长期有效，所以不给裸热链。

| 主题 | 开放教程/权威页面（含示意图） | 说明 |
|---|---|---|
| 协作机器人 / 六轴结构 | [Wikipedia · Industrial robot](https://en.wikipedia.org/wiki/Industrial_robot)、[Wikipedia · Robotic arm](https://en.wikipedia.org/wiki/Robotic_arm) | 通用示意图，插图多为 CC/公有领域，需逐张看授权 |
| 自由度 / 关节、工作空间 | [Wikipedia · Degrees of freedom (mechanics)](https://en.wikipedia.org/wiki/Degrees_of_freedom_(mechanics)) | 概念示意 |
| 坐标系与位姿 | UR 官方 ROS2 文档 · [Robot Frames](https://docs.universal-robots.com/Universal_Robots_ROS_Documentation/rolling/doc/ur_description/doc/robot_frames.html) | **UR 官方图，版权归 Universal Robots**：可“引用页面/成果”，不建议复制图进仓库 |
| 正/逆运动学、奇异 | [UR 官方 DH 文章](https://www.universal-robots.com/articles/ur/application-installation/dh-parameters-for-calculations-of-kinematics-and-dynamics/)（含连杆/动力学图） | 同上：官方图片有版权，引用页面，别复制图 |
| 手眼标定（eye-in-hand, AX=XB） | 开源平台教程（示例）：Realman[中文手眼标定](https://develop.realman-robotics.com/AI/developerGuide/hand/)、[EN Hand-eye Calibration](https://develop.realman-robotics.com/en/AI/developerGuide/hand/)；OpenCV `calibration` 文档 | 取图前核对授权 |
| 相机内参 / PnP | [OpenCV Camera Calibration 教程](https://docs.opencv.org/4.x/dc/dbb/tutorial_py_calibration.html) | 示意图常见 CC/文档许可，需核对 |
| 力传感器 / 重力补偿 | UR 官方传感器 + 力控文档、开源 repo 的 README | 多为官方版权或 repo 自有版权 |
| TCP / 工具中心点 | UR 官方教程（UR Academy）与 [Robot Frames](https://docs.universal-robots.com/Universal_Robots_ROS_Documentation/rolling/doc/ur_description/doc/robot_frames.html) | 官方版权，引用页面 |

---

## 3. 给仓库的推荐做法（防止外链失效）

1. **改为本地图**：把上面“建议取图”里的图下载到 `docs/assets/`，正文用相对路径引用；
2. **保留源头脚注**：每张图下面注明“来源 + 授权 + 作者”；
3. **可复现**：在 `docs/assets/README.md` 里记录每张图的下载源和授权，方便日后替换；
4. **不复制官方版权图**：UR 官方产品照/手册图**不入库**，需要时用文字链接指过去即可。

---

## 4. 我为什么没直接热链更多图

- 本沙箱无法下载图片二进制，且无法可靠核实每个外链的长期有效性与授权；
- 手绘示意图已被你排除；
- 所以只内嵌了**经 Commons API 核实授权**的 DH 图，其余给“开放教程来源清单”由你决定取图方式。
- 若你希望我改走“下载到 `docs/assets/` 再引用”，告诉我一声，但该操作需要在**非本沙箱**的联网环境执行。

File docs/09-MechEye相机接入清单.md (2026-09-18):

# 09 · Mech-Eye 相机接入清单

本机已安装 Mech-Eye SDK `2.5.0`，相机地址为 `192.168.1.33`。当前有效性不以“节点能启动”
判断，而以一次采集的图像、深度和点云元数据判断。

```bash
cd ~/UR10
python3 scripts/setup_mecheye.py --check

# validate_mecheye_capture.py 与 /device_info 都依赖 mecheye_ros_interface 的 srv 类型，
# 该包装在 ~/colcon_ws，而 ~/.bashrc 只 source 了 ~/ros2_ws，必须先手动 source，
# 否则 ros2 会报 "The passed service type is invalid"：
source /opt/ros/humble/setup.bash && source ~/colcon_ws/install/setup.bash
python3 scripts/validate_mecheye_capture.py
# 读型号/序列号/固件（相机节点需先启动）：
ros2 service call /device_info mecheye_ros_interface/srv/DeviceInfo "{}"
```

通过时，将当次 JSON 和生成文件保存到 `outputs/camera/`。确认以下事实：

1. 普通点云 XYZ 是米制浮点数据，存在合理比例的有限点。
2. 组织图、深度图和点云有相同采集批次的时间信息。
3. 所谓颜色/纹理输出是单色，不可把三通道格式当作彩色图。这是 PRO XS 的硬件规格
   （官方规格表 `2D image color: Monochrome`，型号表中 PRO XS 无 `C` 后缀彩色版本），
   不是配置错误；成因与证据见 [`08`](08-六维力与3D相机.md) 与
   `outputs/camera/model-identification-20260918.json`。
4. 相机坐标到机器人 `base` 的变换只能使用已验收的 eye-in-hand 标定参数。

重新安装 SDK、改变 ROS 接口版本或修改相机网络配置后，必须重新执行两条检查命令，并在同一
提交中更新本页、[`08`](08-六维力与3D相机.md) 和 [`../HANDOVER.md`](../HANDOVER.md)。

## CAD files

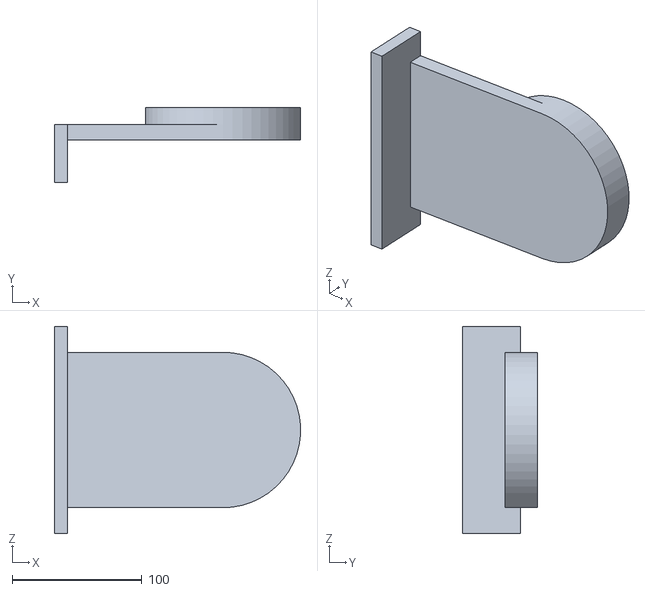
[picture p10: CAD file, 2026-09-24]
model/solidworks/end_effector/末端执行器 - 连接1-1.STL
189.9 x 58.0 x 160.0

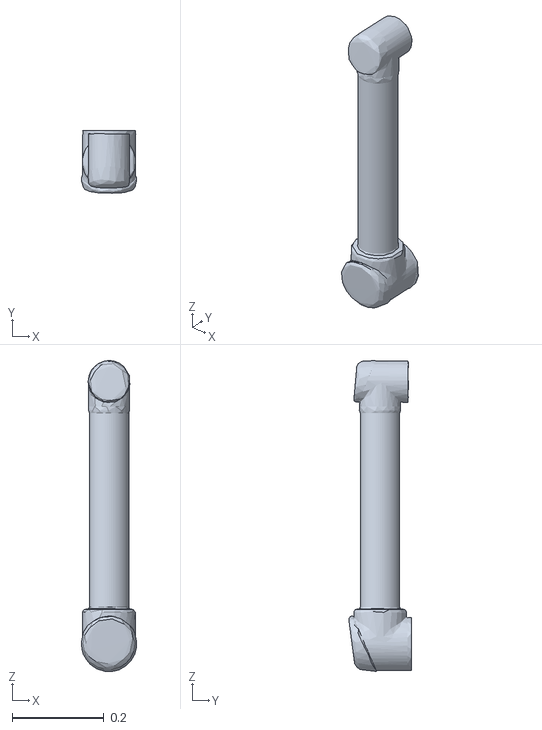
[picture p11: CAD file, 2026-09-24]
model/ur10/forearm.stl
0.12 x 0.136 x 0.678

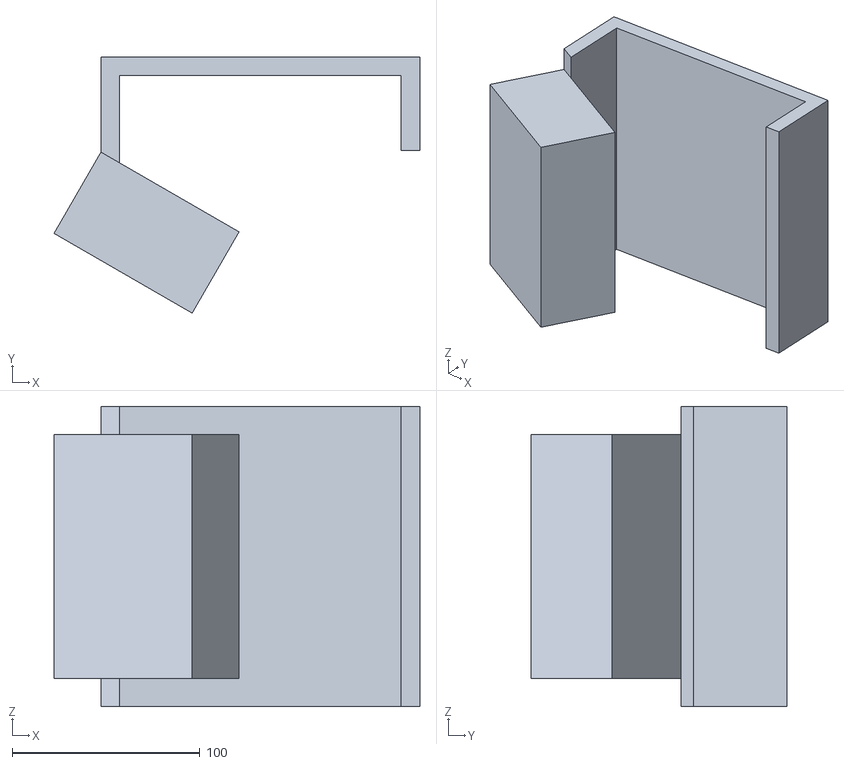
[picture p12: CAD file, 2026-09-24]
model/solidworks/end_effector/末端执行器 - 3D相机-1.STL
195.0 x 136.5 x 160.0

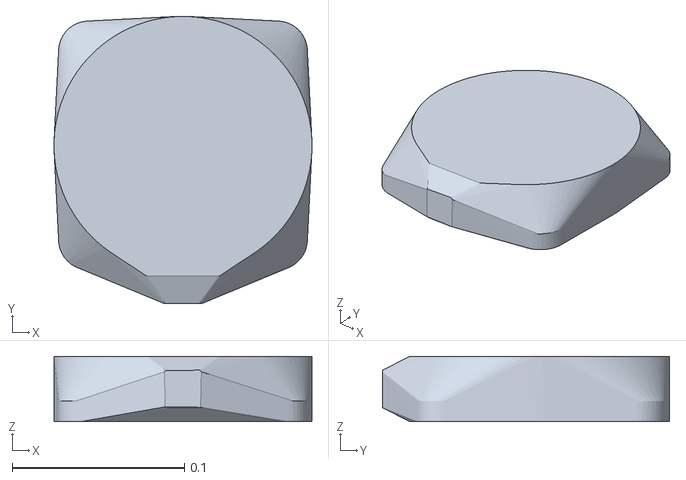
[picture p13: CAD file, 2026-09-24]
model/ur10/base.stl
0.15 x 0.167 x 0.038

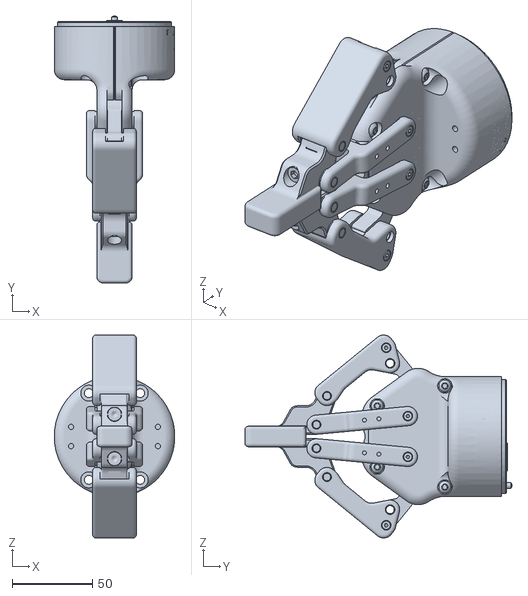
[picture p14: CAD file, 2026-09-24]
model/solidworks/end_effector/末端执行器 - 2F85-CLOSED_20181108.step-1.STL
75.0 x 166.2 x 126.3

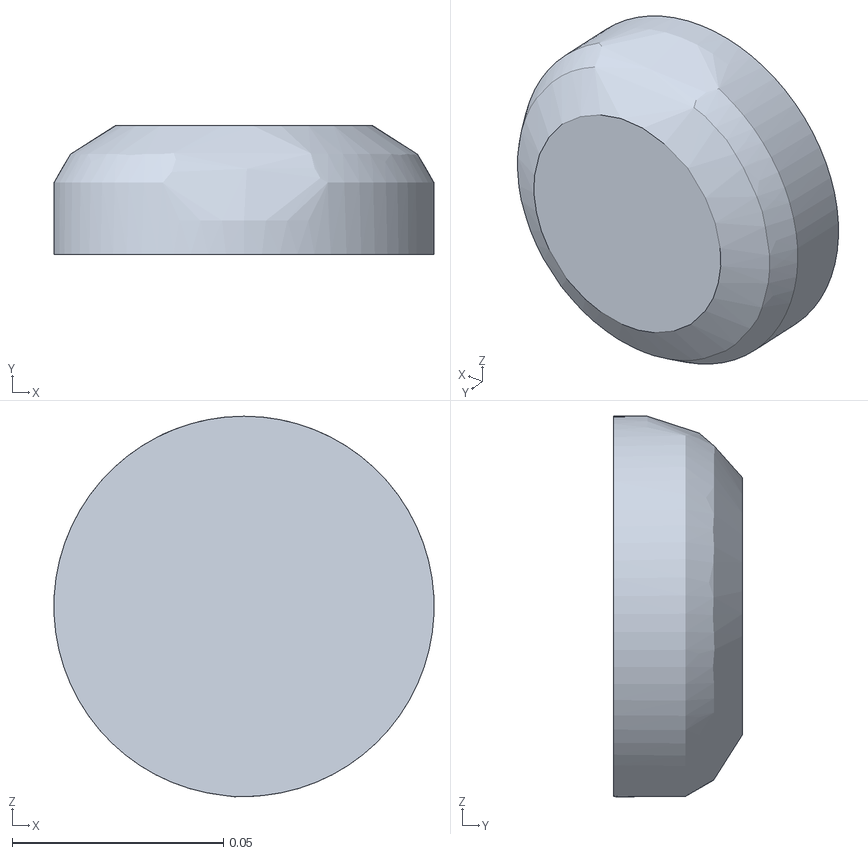
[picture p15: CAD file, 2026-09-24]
model/ur10/wrist3.stl
0.0899 x 0.0305 x 0.0901

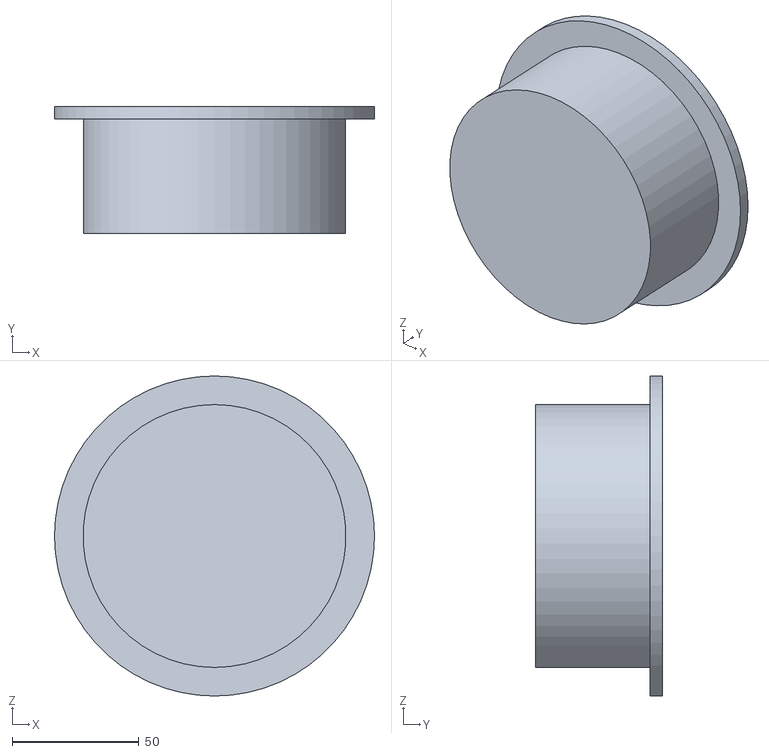
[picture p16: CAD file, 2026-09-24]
model/solidworks/end_effector/末端执行器 - 六轴力-1.STL
126.0 x 50.0 x 126.0

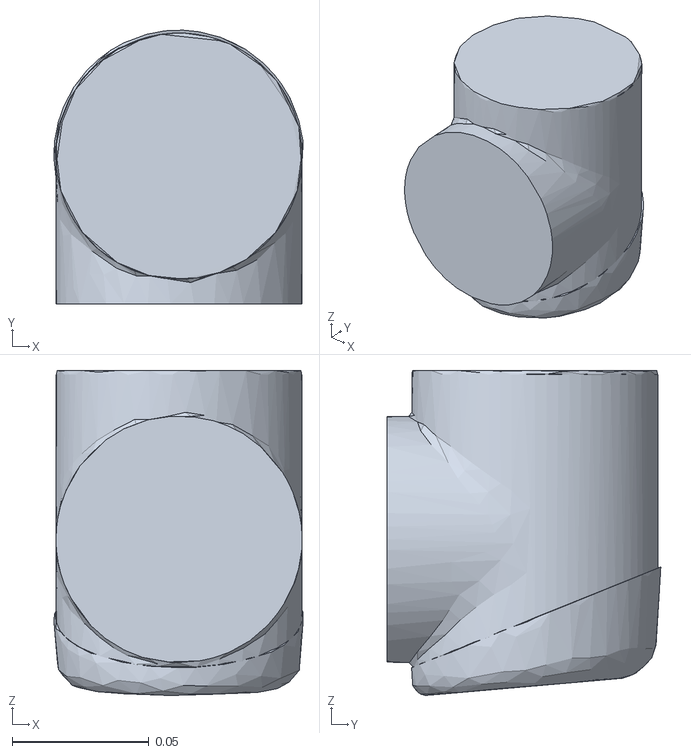
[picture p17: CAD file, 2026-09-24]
model/ur10/wrist1.stl
0.091 x 0.1 x 0.119

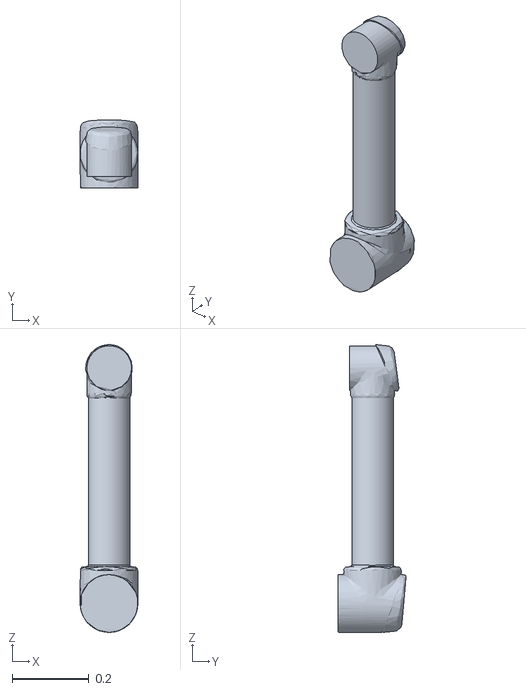
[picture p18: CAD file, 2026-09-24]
model/ur10/upperarm.stl
0.151 x 0.177 x 0.749

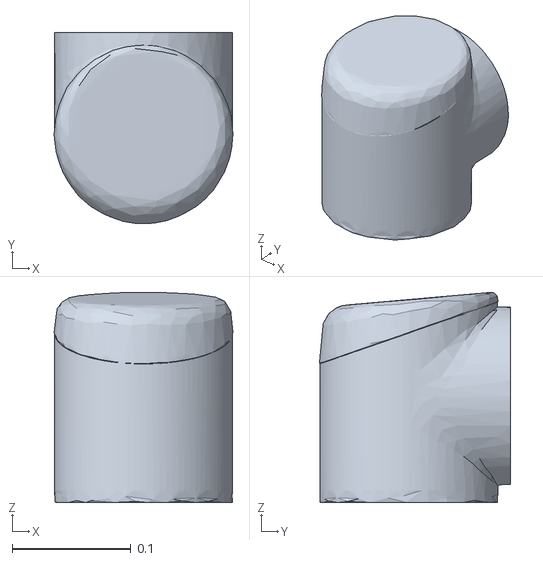
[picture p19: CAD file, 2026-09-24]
model/ur10/shoulder.stl
0.151 x 0.161 x 0.177

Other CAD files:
model/ur10/wrist2.stl

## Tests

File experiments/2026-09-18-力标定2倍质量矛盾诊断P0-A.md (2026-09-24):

# 2026-09-18 P0-A 力标定 2 倍质量矛盾：诊断结果（问题已定性，修复延后）

## 问题（本轮接手时的状态）

- 6 次独立拟合的末端质量高度一致：**3.20–3.29 kg**，条件数 8.2–9.1 在门限内；
- 但 2026-09-10 的**单姿态** `|F|/g` 反推为 **6.56 kg**（`F=(0.39, 11.15, 63.36) N`，`|F|=64.4 N`）；
- 两者相差 **2.03 倍**且极度可重复，`HANDOVER.md` 判为"系统性错误"，怀疑点集中在
  ① 传感器实际 counts-per-force 是否等于驱动硬编码的 `1e6`；② 是否又是"错误 Bias 导致读数翻倍"。

## 本轮只读排查做了什么

1. 直接读传感器**自己的配置**（HTTP 只读，`192.168.1.2/netftapi2.xml`，GET 无副作用，
   不占用 RDT 单消费者流）：拿到 `cfgcpf`/`cfgcpt`/`setbias`/`cfgmr`（量程）/`cfgcalsn`。
2. 用**无 FK、无安装旋转**的独立方法复核质量尺度：静态时传感器读数满足
   `F_i = m·g·u_i + b`（`u_i` = 该姿态下重力在传感器系的方向，`b` = 传感器系内的常量力偏置），
   因此所有姿态的力矢量必然落在**半径 = m·g、球心 = b 的球面**上。对存档姿态做**球面拟合**
   （先线性代数球拟合，再几何 Gauss-Newton 精修）即可**独立**给出 `m·g` 与 `|b|`。
3. 把"单姿态 `|F|/g`"当成估计量，统计它在**全部 68 个存档静态姿态**上的分布。

数据来源：`config/ft_gravity_calibration*.yaml`（6 个批次，含各自 `wrench_mean` 与 `tcp_pose`）。
原始结果：`outputs/ft_calibration/mass-scale-diagnosis-20260918.json`，
传感器配置原件：`outputs/ft_calibration/netftapi2-sensor-20260918.xml`。
复现：`python3 scripts/analyze_ft_mass_scale.py`。

## 结果 1 · 换算常数与硬件 Bias 都**不是**问题

传感器自报配置（`netftapi2.xml`，2026-09-18 读）：

| 字段 | 值 | 含义 |
|---|---|---|
| `cfgcpf` | **1000000** | Counts per Force（N 单位） |
| `cfgcpt` | **1000000** | Counts per Torque（N·m 单位） |
| `setbias` | **0;0;0;0;0;0** | 硬件 Bias 全零 |
| `cfgmr` | 165;165;495;15;15;15 | 量程 Fx/Fy=165 N、Fz=495 N、T=15 N·m |
| `cfgcalsn` / `cfgnam` | FT11885 / "End of line test" | 当前标定与配置名 |

⇒ `scripts/ati_netft_node.py:49-50` 的硬编码 `1_000_000` **等于该传感器自己的标定值**，
单位换算正确，"又写错 Bias 导致翻倍"在本轮也不成立。`netft.txt`（ATI 官方手册，9.3 节）
确认 RDT 记录里的 F/T 就是 counts，必须除 `cfgcpf`/`cfgcpt`，两者取自 `netftapi2.xml`。

## 结果 2 · 2.03 倍是**方法学假象**：单姿态 `|F|/g` 忽略了常量力偏置

球面拟合（每批次独立，全部只用力，不用 FK、不用安装旋转）：

| 数据集 | 姿态数 | 球半径 A=m·g [N] | **m [kg]** | 球心 |b| [N] | 残差 RMS [N] | 单姿态法给的 m [kg] |
|---|---|---|---|---|---|---|
| downward-20260915 | 8 | 34.42 | 3.510 | 24.77 | 0.49 | 5.579 |
| fullrange-20260915 | 12 | 31.84 | 3.247 | 28.95 | 0.93 | 4.440 |
| manual.round2 | 12 | 30.79 | 3.140 | 26.30 | 1.01 | 4.738 |
| manual | 8 | 31.24 | 3.185 | 26.39 | 0.80 | 4.754 |
| mixed-18 | 18 | 31.48 | 3.210 | 35.77 | 2.37 | 5.593 |
| ft_gravity_calibration | 10 | 31.99 | 3.262 | 33.13 | 0.70 | 5.023 |
| **合并** | **68** | **31.89** | **3.252** | **29.59** | 3.16 | 5.055 |

关键事实（对"纯尺度错误"假设的**否证**）：

- 若真的是 2 倍尺度错误（`|F|` 恒等于 m·g、无偏置），则**每个姿态的 `|F|` 必须相同**；
- 实测 68 个姿态的 `|F|` 分布在 **12.34–69.58 N**（跨 5.64 倍），单姿态法给出的质量在
  **1.26–7.10 kg** 之间摆动。**纯尺度错误不可能产生与姿态相关的 `|F|`** ——
  只有"重力 + 传感器系内常量偏置"才能（`|F| ∈ [A−|b|, A+|b|] = [2.3, 61.5] N`，与实测吻合）。
- 6 个批次独立拟合的半径一致落在 30.8–34.4 N（3.14–3.51 kg），与仓库既有多姿态拟合的
  3.20–3.29 kg 一致；2026-09-10 那次单姿态值 6.56 kg 落在"该姿态下 `|b|` 与重力近同向相加"
  的区间内，属**同一现象的另一个采样点**，不是第二个独立测量。

**结论**：矛盾的 2.03 倍不是传感器/换算/负载错误，而是**用 `|F|/g` 单姿态反推质量时忽略了
约 25–36 N 的常量力偏置**。量纲与尺度均无需修正；`1.0 N` 门限的单位没问题。

## 结果 3 · 仍然开放（按用户决定**延后**，本轮不推进）

1. **那 ~29.6 N 常量偏置的物理来源未定**：可能是传感器零点、线缆/气管侧向力、安装预载
   或标定配置（`cfgnam = "End of line test"`）残留。**注意**：它加在传感器系内，姿态变化时
   不变，所以不影响上面关于尺度的结论，但会直接影响"无外力时应为零"的验收判据。
2. **绝对牛顿尺度仍依赖质量基准**：`cfgcpf = 1e6` 只证明驱动与传感器规格一致。
   控制器回读 `3.5 kg / [0,0,0.1] m` 与拟合值 3.25 kg 同量级（差 ~0.25 kg，量级上正是
   传感器近端半体的自重），可作旁证，但按 `HANDOVER.md` 规定**不算独立测量**。
3. **第 5 节的物理一致性门禁要改写法**：原计划"拟合质量须与单姿态 `|F|/g` 一致（<5%）"
   这条门禁**本身是错的**（单姿态法在数学上无效）。正确写法：用**未参与拟合的多姿态**
   残差 + 球面拟合半径与偏置的**可辨识性**（姿态方向覆盖）作为门禁。

## 本轮顺带产出的可复用数据

- 2026-09-18 传感器实时 counts（`runft = 3508496;6698978;59880314;2310797;2439826;165029`）
  ⇒ 当时读数 `F=(3.508, 6.699, 59.880) N`、`T=(2.311, 2.440, 0.165) N·m`。这是**新增的
  独立静态样本**，可与上述球面模型核对（该姿态未参与拟合）。
- 上述 XML 也确认 `setflt/IIR`、`setrate = 7000`（内部采样率）等参数，供第 5 节时延测量参考。

## 复现命令（全部只读，不动机械臂）

```bash
cd ~/UR10
python3 scripts/analyze_ft_mass_scale.py
python3 scripts/verify_ur_payload.py
```

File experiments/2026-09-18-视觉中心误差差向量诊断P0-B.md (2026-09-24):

# 2026-09-18 P0-B 视觉候选中心 35.84 mm：差向量诊断（查出一个 50 mm 符号错误）

## 结论摘要

1. **差向量不是"两轴各偏半个边长"**。base 系差向量 `(+31.36, -17.36) mm`（模长 35.84 mm）；
   换算到棋盘格（target）系是 `(Δx, Δy) = (-36.22, -13.94) mm`。计划草案 §3 P0-0 假设的
   "两个轴各偏一个半边长 ⇒ `√(25²+25²)=35.36 mm`"**只对模长巧合，分量完全不符**
   （若是两轴各偏半边长，target 系两个分量都应 ≈25 mm）。
2. **查出一个硬错误：偏移符号反了 50 mm**。存档的可见竖直侧面位于 target `x = +0.0528 m`；
   相机原点在 target `x = +0.3641 m` 且光轴指向 `-x`。凸体只能看见**法向朝向相机**的面，
   所以立方体必须在侧面的**另一侧**：`x_c = 0.0528 − 0.025 = 0.0278 m`。
   而 `locate_cube_near_checkerboard.py:100` 用的是
   `outward = sign(侧面中心 − 棋盘格中心[横向轴])`（+1），得到 `x_c = 0.0778 m` —— **差了 50 mm**。
   该启发式在本场景没有几何意义：立方体相对棋盘格是沿 **-y** 方向偏 ~110 mm 摆放的，
   横向轴却是 x。
3. **尺寸先验从未被测量验证**。可见侧面的测量跨度：y 向 `44.28 mm`（p5–p95）、高度被
   "高出棋盘格 20–80 mm"的掩膜截断（实测 ≥25 mm）。用 44.3 mm 的观测去套"50 mm 标称边长"
   本身就有 ~6 mm 级风险，而脚本里 `+0.025` 是硬编码的。
4. **"真值"本身不成立，不能当验收基准**。符号改对后与人工确认抓取点的残差为 **22.2 mm**
   （符号错时 35.84 mm），两者都不为 0；更关键的是：无论哪种符号，都与"50 mm 立方体 +
   单个可见侧面"**几何自洽性矛盾**（人工点会把平面推到立方体内部）。人工点是一次示教器
   "目测摆正"的位置，夹爪本身允许几毫米偏心，其不确定度未量化。

⇒ 修法**不是**"减掉 25 mm"，而是把中心**测量**出来（顶面平面 + 足印 + 实测边长），
并用**独立基准**在**多个重新摆放位置**验收。

## 证据

### 差向量（`outputs/vision/center-error-diagnosis-20260918.json`）

| 量 | 值 |
|---|---|
| 视觉候选中心 base XY | `(0.630251, -0.099233) m` |
| 人工确认抓取点 base XY | `(0.661610, -0.116590) m` |
| **差向量（人工 − 视觉）** | `(+31.359, -17.357) mm`，模长 **35.842 mm** |
| 方向 | base `X+ / Y-`（与现场观察一致） |
| target 系分量 | `(-36.22, -13.94) mm`（不是 25/25） |

### 符号检查

| 量 | 值 |
|---|---|
| 可见侧面所在轴 | target `x`（法向厚度仅 `0.295 mm`） |
| 侧面位置 | target `x = +0.052758 m` |
| 相机原点（target 系） | `(+0.364116, -0.041081, -0.097257) m` |
| 相机光轴方向（target 系） | `(-0.9343, -0.0854, +0.3461)` ⇒ 朝 **-x** 看 |
| 结论 | 相机在 **+x** 侧 ⇒ 立方体体心在 **-x** 侧 ⇒ `x_c = 0.0528 − 0.025 = 0.0278 m` |
| 旧脚本给的符号 | `+`（`x_c = 0.0778 m`）⇒ **符号错误，差 2×0.025 = 50 mm** |

### 修正符号后的残差

| 量 | 值 |
|---|---|
| 符号修正后中心 base XY | `(0.680011, -0.104091) m` |
| 与人工确认点残差 | **22.245 mm**，向量 `(-18.40, -12.50) mm` |
| 物理自洽性 | 22 mm 残差无法由"50 mm 立方体 + 单可见侧面"解释 ⇒ 真值来源本身不可信 |

## 修复：改为"测顶面"，并加硬门禁

新增 `scripts/measure_cube_geometry.py`（纯几何核心与采集分离）：

```
参考面（物体周围的环，排除棋盘格区域）  ->  站立面
组织点云连通域                         ->  物体候选
RANSAC 顶面（法向须与棋盘格面平行）     ->  足印 + 实测边长
中心 = 足印中心 − (h/2)·上法向
```

硬门禁（不满足就**拒识**，绝不静默给中心）：点数下限、顶面存在且与棋盘格面平行
（≤12°）、覆盖率 ≥0.85、足印接近正方形（长宽比 ≤1.10）、参考面存在且低于顶面。
**标称尺寸先验单独报告**：实测边长与 `--expect-edge` 不符时状态为
`measured_size_prior_mismatch`，不会静默放行。另外用 3×3 邻域去孤立飞点
（结构光边缘混点会把最小外接矩形撑大、伪装成"50 mm"）。

### 离线数值门禁（合成射线投射场景，无需相机/机器人）

`python3 scripts/test_measure_cube_geometry.py` → `outputs/vision/measure-cube-offline-selftest-20260918.json`

场景模型：针孔栅格对"桌面 + 棋盘格板 + 偏航立方体"做**射线投射**，取最近命中 ⇒ 自带
遮挡、孔洞，只看得见顶面 + 1~2 个侧面（正是真机的情形），再叠加测距噪声、丢点与飞点。

| 用例 | 期望 | 结果 | 中心误差 | 实测边长 |
|---|---|---|---|---|
| 斜视、50 mm 立方体 | measured | ✅ measured | **0.51 mm** | 51.16 / 50.40 mm |
| 实际 45 mm、先验仍写 50 | 标出先验不符 | ✅ `size_prior_mismatch` | 0.47 mm | 46.34 / 45.32 mm |
| **掠射视角（只见侧面）** | **必须拒识** | ✅ rejected | — | — |
| 噪声 0.6 mm + 30% 丢点 + 2% 飞点 | measured | ✅ measured | 0.61 mm | 52.16 / 51.32 mm |
| 棋盘格为 5 mm 厚板（站立面是桌面） | measured | ✅ measured | 0.31 mm | 50.98 / 50.48 mm |
| 立方体偏航 20° | measured | ✅ measured | 0.40 mm | 51.32 / 50.85 mm |

**6/6 通过；其中"掠射视角必须拒识"正是 2026-09-17 出错的那一类视图**——旧脚本在这种视图下
仍会给出一个中心。边长测量存在 ~1.2 mm 的系统性偏大（结构光边缘混点），故门限取 ±2.5 mm。

## 还不能算验收的部分（下次现场清单）

1. **采集必须落盘原始点云**。2026-09-17 只存了摘要 JSON，点云没存 ⇒ 无法离线复核，
   这是本轮最大的证据缺口。新脚本支持 `--save-cloud`（npz）。
2. **独立真值**。人工目测点不合格。可选：(a) 游标卡尺/钢板尺实测立方体与棋盘格相对位置；
   (b) 落盘点云后用顶面 + 侧面联合解算并交叉验证；(c) 夹爪轻触/下压的法向接触点。
3. **多个重新摆放位置**各采一次，报告中心误差分布（不是只报点云拟合残差）。
4. 现场棋盘格已移动（用户 2026-09-18 确认）：新采集必须**同一帧**同时看到棋盘格与物块，
   target 系由该帧 PnP 重建，不依赖 09-17 的绝对坐标。
5. 机械臂当前位姿（TCP `0.647, -0.268, 0.276`）看不到 09-17 那套场景；采集需要现场用
   示教器把臂点动到能同时看到棋盘格与物块的位姿（只读采集，不发运动指令）。

## 复现命令（全部只读/离线，不动机械臂）

```bash
cd ~/UR10
python3 scripts/analyze_cube_center_error.py      # 差向量 + 符号检查
python3 scripts/test_measure_cube_geometry.py     # 离线数值门禁（6/6）
# 现场采集（需相机已启动，且机器人静止）：
python3 scripts/measure_cube_geometry.py --capture --save-cloud outputs/vision/clouds/cube-<tag>.npz
python3 scripts/measure_cube_geometry.py --npz outputs/vision/clouds/cube-<tag>.npz   # 离线复算
```

## 与旧结论的关系

- `experiments/2026-09-17-立方体视觉定位候选.md` 与
  `experiments/2026-09-17-视觉候选人工修正抓取.md` 保留原样（历史记录）；
  本文修正其中"向远离棋盘格方向偏移 25 mm"这一步的**符号**与"50 mm 标称边长"的**依据**。
- `experiments/2026-09-18-八节课实施计划草案.md` §3 P0-0 的"两轴各偏半边长"假设**被本文否证**
  （模长巧合 35.36≈35.84，分量 36.22/13.94 不符）。计划里"用顶面 + 最小外接矩形 + 覆盖率门禁"
  的正确算法部分**被保留并实现**。

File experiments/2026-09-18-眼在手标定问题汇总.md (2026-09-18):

# 2026-09-18 眼在手（eye-in-hand）标定：本轮问题汇总与修复

本轮任务：棋盘格被移动 ⇒ 重标手眼 + 独立验收。执行过程中**连续踩到 13 个问题**，
其中 3 个是硬件层面的（两次线缆、一次相机自碰撞）。本文件把它们集中整理，附数值证据与修复状态。

> 相关详细记录：
> - [`2026-09-18-眼在手棋盘格重标定.md`](2026-09-18-眼在手棋盘格重标定.md)（主记录：门禁、采样、改版全过程）
> - [`2026-09-18-相机链路复核-沙箱共享内存伪故障.md`](2026-09-18-相机链路复核-沙箱共享内存伪故障.md)（问题 1 的完整判别实验）

---

## 一、问题总览

| # | 问题 | 类别 | 影响 | 状态 |
|---|---|---|---|---|
| 1 | 相机采集链路"故障"实为受限 shell 的 FastDDS 传输问题 | 环境误判 | 挡住了整个视觉流程 | ✅ 已定位，有 10 秒判别法 |
| 2 | 09-17 标定只存摘要：全量机器人帧与点云都没存 | 证据缺口 | 事后无法离线复核 | ✅ 已修（新采集器） |
| 3 | 棋盘格被移动 ⇒ 旧标定绝对坐标失效 | 前提失效 | 必须重标 | ✅ 计划已重锚 |
| 4 | 新代码重现"约定反向"错误（同类于 50 mm 符号错误） | 代码缺陷 | 读数全错 | ✅ 已修 + 补钉子自检 |
| 5 | 执行器"到位"判据只查位置不查姿态 | 代码缺陷 | **指令叠加、运动异常** | ✅ 已修 |
| 6 | 执行器按槽位号顺跑，而非门禁验证的访问顺序 | 代码缺陷 | 会重犯门禁已排除的失败 | ✅ 已修（忠实重放） |
| 7 | 恒定滚转把腕关节拧死 ⇒ **勒紧相机线缆** | 设计缺陷 | **现场两次拉线 / 保护停** | ✅ 已缓解（腕部连续滚转），净绞紧仍在 |
| 8 | 门禁完全没有**自碰撞**模型 ⇒ **相机撞到机械臂** | 设计缺陷 | **现场一次实体接触** | ✅ 已加网格级门禁（路径逐点） |
| 9 | URScript 只发 `def ... end` 不会执行 | 代码缺陷 | 第一次真机会完全不动 | ✅ 已修 |
| 10 | FK 一致度是 2.5 mm，不是文档里的 0.017 mm | 文档口径 | 引用会失真 | ✅ 已在门禁中写明 |
| 11 | 相机节点必须单实例；ATI 是单消费者 | 资源冲突 | 采集不可预测 | ✅ 已收敛 |
| 12 | 有线网卡断链 ⇒ 机器人流量被 VPN 接管 | 环境/安全 | 全部真机阶段阻塞 | ✅ 现场已恢复 |
| 13 | 腕部连续性的目标写法有顺序依赖性 | 算法缺陷 | 优化收益被抵消 | ✅ 改为绝对锚定 |

---

## 二、逐条说明

### 1. 相机采集链路"故障"是伪故障（受限 shell 的 FastDDS 共享内存）

**现象**：`ros2 service call /device_info` 40 s 无响应；`validate_mecheye_capture.py` 抛 `TimeoutError`。
审计文档一度记为"相机链路故障"。

**判别实验**（不碰硬件的 trivial 对照）：

- 连**原生 rclpy 服务**（`describe_parameters`，完全不碰 SDK）也无响应；
- 自建 trivial `std_srvs/Trigger` 服务：**`wait_for_service` 立刻返回 True，但调用永不返回**；
- 两个纯 Python 节点之间话题**收到 0 条**。

⇒ 发现（UDP 多播）正常、用户数据不通。根因：该 shell 环境的 `/dev/shm` 是**每次调用私有的 tmpfs**
（上一调用写的文件下一调用就消失），Fast DDS 默认优先走共享内存传输，段名匹配得上却共享不到内存。

**验证**：`export FASTDDS_BUILTIN_TRANSPORTS=UDPv4` 后最小服务立即返回、话题收到 **24 条**；
相机侧 `/device_info` 正常应答、采集全流程通过（点云 1310720 点、`bgr_identical_fraction=1.0` 再证单色）。

**结论**：相机、SDK、IP 直连、ROS 服务机制**全部正常**；与 SDK 打印的 `/var/log` 无写权限**无关**。
**判别法**：遇到"服务/话题列得出来但调用无响应"，先试 `FASTDDS_BUILTIN_TRANSPORTS=UDPv4`，10 秒出结论。

### 2. 09-17 标定的证据缺口

旧样本目录只有 `image.png` + `corners.png` + 摘要 JSON —— **76 帧机器人状态被压成 4 个数，完全没有点云**。
⇒ 出问题只能重采，无法回头核对。**这是那次最大的方法学缺陷。**

已修（`scripts/collect_handeye_sample.py`）：每个样本现在落 `image.png` + `corners.png`
+ **`robot_frames.json`（全量 352 帧 @125 Hz）** + **`cloud.npz`（原始组织化点云 7.0 MB）** + `sample.json`。

### 3. 棋盘格被移动

当前位姿 `detected=False`（0/54 角点），旧标定的绝对坐标全部失效 ⇒ 必须重标。

### 4. 新代码里的"约定反向"错误（与 09-17 的 50 mm 符号错误同类）

球坐标函数的平移语义与 `solvePnP` 相反：一个当"相机在靶标系的坐标"，
另一个当"靶标在相机系的坐标"。

- **表现**：真实样本被读成 `tilt 173.8°`（应为 28.0°）。
- **原有自检抓不到**：它只验证"算出去再算回来能对上"，把语义整个反向也能通过。
- 修法：按真实语义改名 `target_from_camera_from_spherical` / `spherical_from_target_from_camera`，
  所有持有流水线 `camera_from_target` 的调用点先取逆。
- **补了两条钉住约定（而非只验自洽）的自检**：①`camera_from_target` 必须把靶标放在相机前方（+z）
  且模长=距离；②流水线约定下的参数还原 <1e-6。
- **验证**：修复前后计划的 26 个 TCP 目标**逐位不变** ⇒ 计划一直是对的，错的只是读数层。

### 5. 执行器"到位"判据只查位置不查姿态

**纯转动段的 TCP 线速度天然≈0**，所以每个 `reorient` 段都在 0.0–0.2 s 内被误判"到位"
（实测姿态只变了 `0.00009 rad`），下一条 `movel` 在转动未完成时就发出，两条运动叠加 ——
第 17 槽的 `translate` 段因此把 1.7 rad 的姿态变化挤了进来，28.6 cm 只走了 13 cm 就超时。

修法：到位判据改为**位置 + 姿态 + 线速度 + 角速度四项同时满足**
（1.5 mm / 0.006 rad / 0.003 m·s⁻¹ / 0.02 rad·s⁻¹），并加**停滞检测**。
`pose_error()` 已单元验证（同一姿态 / 纯平移 / 纯转 90° / 转 1.7 rad 四种情形全对）。

### 6. 执行器按槽位号顺跑，而非门禁验证的顺序

门禁验证的是**特定访问顺序**（关节空间最近邻 + 逐槽救援滚转），执行器却按槽位号顺跑 ——
那恰好是门禁证明会失败的情形（实测：某位姿单独评估 PASS，紧跟另一槽却 FAIL）。

修法：执行器**逐段重放门禁 JSON 里的段列表与顺序**，不自行重算路径；
并加一致性校验（门禁后机械臂漂移 >0.02 rad 或首段起点差 >15 mm 即拒绝执行）。

### 7. 恒定滚转把腕关节拧死 ⇒ 勒紧相机线缆 ★硬件问题

原计划 26 个位姿全用同一滚转（190°，按"法兰最高"选出的）。对门禁轨迹逐段求 IK 统计腕关节 J6：

| 方案 | J6 净变化 | J6 累计行程 | J6 范围跨度 | 最大单段 |
|---|---|---|---|---|
| **原计划（26 槽恒定 190°）** | −144.3° | **2140.3°** | 315.5°（**顶到 −360° 限位**） | **191.6°** |
| 360° + 绝对锚定 J6 | +296.4° | 957.5° | 405.1° | 95.1° |
| **180° 半圈 + 绝对锚定** | +296.4° | 983.6° | **358.3°** | **72.7°** |

⇒ 原计划会把腕关节累计拧 6 圈并顶到硬件限位，**这正是勒紧相机线的机制**。
现场对应两次事件：一次保护停（机械臂拉到自己线缆、受力触发）、一次转动被线拉住
（`reorient` 要转 81.6°，只转了 37.6° 就停在原地，位置/方向都对）。

改版：滚转目标改为**腕部连续**（`--roll-objective wrist`）+ 绝对锚定；
法兰硬下限提到 **0.25 m**；方位跨度收到 **180°**（仍是 8 个不同方向）。
结果：累计行程 −55%、最大单段 −62%、**不再顶 J6 限位**。

**必须说清的局限**：上述 J6 是**标称 URDF 的 IK 推算**，不是控制器实际关节角（同一笛卡尔位姿有多个
IK 解，控制器按自己准则选分支）。因此给执行器加了**实际关节角记录**（从 30003 的 `q_actual`
直接读 J6 的起点/终点/净变化/累计行程/跨度）——真结论要用实跑数据说话。
**另外**：力通道抓不到线缆卡阻（实测 \|F\| 变化仅 **1.69 N**，而阈值是 25 N），
真正拦住它的是**停滞检测**。

### 8. 门禁完全没有自碰撞模型 ⇒ 相机撞到机械臂 ★硬件问题

移动门禁原本只查可达性、关节限位、奇异度、法兰高度 —— **没有自碰撞**。
现场发生 3D 相机实体接触机械臂。相机挂在 `tool0` 外侧 **~0.33 m**（`tool0_from_camera`
平移 `[0.046, 0.252, 0.202]` m，与现场"侧向 30 cm"一致），外壳约 **20×20 cm**，
臂回折时**必然能够到自己的传感器**。

**先试过的错路**：胶囊骨架（用 FK 关节原点 + 保守半径）—— 在"机器人确实动过、没出事"的位姿上
恒定报重叠 −64 mm，因为夹爪的胖胶囊永久插在前臂胶囊里。**已废弃**。

**正确做法**（`scripts/self_collision.py`）：加载 URDF 自带的**真实碰撞网格**
（`ur_description` 的 7 个 STL），相机按 20×20 cm 外壳 + 50 mm 支架建成盒子，
用 hppfcl 求实际距离。**模型经现场事件验证**：

| slot | 间隙 | 最接近 |
|---|---|---|
| **7**（相机真的撞到臂） | **−2.1 mm** | camera_housing vs forearm |
| **5**（转动被拉住） | **−25.6 mm** | camera_bracket vs forearm |
| 8 / 12 | −40.6 mm | camera_housing vs forearm |

26 个位姿里 **8 个重叠（负间隙）**，另 3 个低于 30 mm ⇒ **这批位姿按当前相机安装做不出来**。

**修复与门禁**：自碰撞间隙成为**硬门禁**，与法兰高度、IK 可行性一起约束滚转选取；
并且**在路径的每个采样点检查**（不只看端点 —— 实测出事那次两端的间隙都是可接受的）。
加上门禁后重选计划：22 个可行位姿的相机间隙 **47.5–64.3 mm**（门限 40 mm），法兰 ≥0.2507 m。

**一个坑**：验证时必须用**计划实际采用的 IK 分支**（计划 JSON 里存 `roll_selection.q_rad`），
用 `np.zeros(6)` 重新解会落到别的分支，得到完全不同的间隙值（我一开始就这么错了）。

### 9. URScript 只发 `def ... end` 不会执行

必须显式调用。仓库里 `position_pick_place.py`（真机跑通抓放闭环的那个）用的是
"def + 调用行"的写法；`ur_relative_movel.py` 只发 def 且**连结果文件都不存在**，
说明它从未被真机跑过，不能当依据。已补上调用行（并在代码注释里说明原因）。

### 10. FK 一致度口径

实测 **0.002510 m / 0.003585 rad**（标称 URDF）。交接文档里 `0.017 mm` 那条用的是
**工厂标定文件** `config/ur10_factory_calibration.yaml`。2.5 mm 对"把相机摆到板前 0.35 m"
完全够用（板宽 60 mm、容差厘米级），但**必须写明来源，不能当 0.017 mm 引用**。

### 11. 相机节点单实例 / ATI 单消费者

现场出现过两个相机节点实例同时占用同一台相机。ATI 已知是单消费者（UDP 49152），
**相机同理**。已收敛为：相机节点由一个终端持有，客户端只做 UDP 侧通信。

### 12. 有线网卡断链 ⇒ 流量被 VPN 接管

```
enp0s31f6  DOWN（NO-CARRIER, carrier=0）        ← 原本 UP 192.168.1.10/24
ip route get 192.168.1.3 → via 172.18.0.2 dev singbox_tun table 2022
```

`192.168.1.0/24` 直连路由消失，到机器人/相机的流量被 sing-box 策略路由接管走隧道：
`ping` 仍通、裸 TCP 也能建立，**但数据流不可靠**（状态读取全部超时）。
**现场真实原因**：机械臂拉到了自己的线缆、受力触发保护停。
恢复判据：`ip -brief addr` 里 `enp0s31f6` 重新拿到 `192.168.1.10/24`，
`ip route get 192.168.1.3` 指向 `dev enp0s31f6`。**未擅自改动路由或 VPN 配置。**

### 13. 腕部连续性目标的顺序依赖性

"最小化相对上一个位姿的 J6 增量"是**顺序相关**的，而滚转优化顺序与门禁执行顺序不一致 ⇒
收益被抵消（实测净绞紧仍 +222°）。改为**绝对锚定**（所有位姿的 J6 贴近起始 J6），顺序无关。

---

## 三、本轮新增工具

| 脚本 | 作用 |
|---|---|
| `scripts/analyze_handeye_closure.py` | 独立验收：固定棋盘格闭环、54 角点世界散布、重投影门限、**不经手眼变换**的点云逐角点交叉校验 |
| `scripts/handeye_pose_advisor.py` | 点动/运动导航：球坐标 ↔ 变换、目标 TCP 位姿表、覆盖率、"下一个空槽位"；含 IK 感知与自碰撞感知的滚转选取 |
| `scripts/check_handeye_plan_observability.py` | 采集前的姿态分布可观性门禁（rank / 零空间间隔 / 旋转轴各向同性 / 法兰高度） |
| `scripts/check_move_plan.py` | **运动离线门禁**：FK 一致度、逐点 IK、关节限位、奇异度、法兰高度、**相机自碰撞（逐采样点）**、路径密采样、访问顺序、保底救援 |
| `scripts/run_move_plan.py` | 真机执行：**忠实重放**门禁轨迹、位置+姿态到位判据、**看门狗**（直线不变量 + 力变化）、自动采集、实际关节角记录 |
| `scripts/self_collision.py` | 网格级相机-机械臂自碰撞（URDF 碰撞网格 + hppfcl） |

## 四、离线门禁结果

| 门禁 | 结果 |
|---|---|
| 闭环分析自检 | **8/8 PASS** |
| 点动导航自检 | **7/7 PASS** |
| 计划可观性 | rank **8**（良态）、8 个方位扇区铺满 |
| 物块测量离线门禁 | **6/6 PASS** |
| 09-17 真实数据回归 | Park 留出 **2.642 mm / 1.051°**、Park-vs-Horaud **0.391 mm / 0.232°** —— 与旧 yaml **逐位一致** |
| L2 单段低速真机 | **PASS**：Z 位移 **49.8585 mm**（指令 50）、到位误差 **0.143 mm**、最大路径偏离 **0.114 mm**、\|F\| 变化 **0.91 N** |
| 真机首个样本 | **54/54 角点、重投影 0.1335 px、位置差 0.0 mm、姿态差 0.01°** |

## 五、仍未解决 / 待现场决策

1. **净绞紧仍在**（模型约 +296°）。拆步（单段姿态变化 ≤20°）只能把勾到的后果限制在短步内，
   **根治要动线缆走线**（给相机线留足余量、避免绕腕）。
2. **自碰撞门禁的相机几何是现场口述尺寸**（20×20 cm 外壳、30 cm 支架）。
   建议实测外壳三边与支架走向后更新 `self_collision.py` 的参数。
3. **样本量不足**：目前仅 **1 个**已采样本。自碰撞门禁后可行位姿 22 个，
   仍需 ≥20 个接受样本 + 冻结后独立样本 + 物块测量多位置验收。
4. **末端执行器/夹爪几何**（tool0 之外的伸出长度与半径）尚未实测，会影响自碰撞余量。
5. **示教器安全配置的 Force 限值**未记录（现场那次"受力触发保护"说明它是开启的），
   建议在报告里写明数值。

---

## 六、可直接复用的经验

1. **区分"环境假象"与"真实缺陷"要靠判别实验**，不是靠猜：一次 trivial 对照（不碰硬件）
   就能把"相机坏了"改成"传输层断了"。
2. **自检必须钉住约定，不能只验自洽**。只验"算出再算回"的自检，对"整体语义反向"是盲的。
3. **真机门禁必须验路径，不是验端点**：`movel` 走直线，端点可达而路径不可达是常态；
   自碰撞同理（出事那次两端间隙都合格）。
4. **"可达性"还依赖访问顺序**：某位姿单独可达，紧跟另一槽却不可达 ⇒ 顺序是计划的一部分。
5. **自由自由度要用来同时满足多条判据**：滚转既能抬法兰、也能护线缆、也能避自碰撞，
   但一次只优化一条会顾此失彼（恒定 190° 就是这样把腕子拧死的）。
6. **模型推算不能当实测**：J6 绞紧量必须用控制器 `q_actual` 验证；
   力通道对线缆卡阻不敏感（1.69 N vs 25 N 阈值），真正管用的是停滞检测。

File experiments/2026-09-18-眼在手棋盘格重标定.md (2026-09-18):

# 2026-09-18 眼在手（eye-in-hand）棋盘格手眼标定重标定

本轮目标：棋盘格 2026-09-18 已被移动 ⇒ 09-17 标定的绝对坐标失效，必须**重标 + 独立验收**。
本文件按"资料依据 → 离线数值门禁 → 真机采集 → 独立验收"分层记录，**每层都留数值证据**。

状态：**进行中**（采集尚未开始，见最后一节）。

---

## 一、参考依据

| 项 | 值 / 来源 |
|---|---|
| 方法论 | OpenCV `calibrateHandEye`，Park（主）+ Horaud / Tsai（交叉）。沿用 09-17 已验证的实现 |
| 棋盘格 | 10×7 方格、9×6 内角点、格长标称 6 mm |
| 旧标定 | `config/handeye_eye_in_hand_20260917.yaml`（Park，`tool0_from_camera`，15 训练 + 5 留出） |
| 视觉几何已知错因 | `experiments/2026-09-18-视觉中心误差差向量诊断P0-B.md`（单可见侧面推中心的 50 mm 符号错误；"50 mm 标称边长"从未被实测验证） |
| 相机链路 09-18 异常复核 | `experiments/2026-09-18-相机链路复核-沙箱共享内存伪故障.md`（**伪故障**，见下） |

---

## 二、真机前置状态（2026-09-18 11:14–11:30，全部只读）

| 检查 | 结果 |
|---|---|
| `scripts/diagnose.py` | 网络 / 29999 / 30001 / 30002 / 63352 全 OK；`robotmode RUNNING`、`safetystatus NORMAL`、`programState STOPPED` |
| `scripts/read_ur_state.py` | RUNNING / NORMAL；TCP(11:14) `(0.647433, -0.268464, 0.326105)` |
| `scripts/check_current_docs.py` | 通过（18 个 Markdown） |
| `scripts/test_measure_cube_geometry.py` | 离线门禁 **6/6 PASS**（含"掠射视角必须拒识"） |
| 相机链路 | **正常**。审计 §3.2 的"服务无响应"是 DSH 沙箱私有 `/dev/shm` 打断 FastDDS 共享内存传输所致；`export FASTDDS_BUILTIN_TRANSPORTS=UDPv4` 后 `/device_info` 与 `validate_mecheye_capture.py` 全部通过。详见专门记录 |
| 并行 agent | 另一 DSH 会话（`probe_script4`）在 11:18–11:19 修改 `scripts/ros_web_bridge.py`、`scripts/start_dashboard.sh` 并启动仪表盘+ATI。它不碰手眼、不给机器人发运动指令 |
| 棋盘格可见性 | 11:20 时 `check_handeye_checkerboard.py` → `detected=False`（0/54），此后现场点动到位姿，11:28 已 54/54 可见 |

---

## 三、本轮工具改动（补 09-17 的最大证据缺口）

09-17 只存 `image.png` + `corners.png` + 摘要 JSON：76 帧机器人状态被压成 4 个数，且**没有点云**
⇒ 无法离线复核。本轮改如下。

### 3.1 `scripts/collect_handeye_sample.py`

- **新增 `robot_frames.json`（默认写）**：完整 30003 帧日志（`monotonic_s / q_rad / tcp_pose / tcp_velocity`），
  不再只留均值。`--no-robot-frames` 可关闭。
- **新增 `--save-cloud`**：额外触发 `/capture_point_cloud`，把**原始组织化点云**（相机系 `camera_xyz_m`，float32）
  连同 `k / d / corners_px / camera_from_target / base_from_tool0 / inner_corners / square_size_m`
  一起写成 `cloud.npz`。为此把 payload 构造抽成模块级 `build_cloud_payload()` / `save_cloud_npz()`，
  使离线自检能复用同一 schema（不复制粘贴）。
- 每个样本目录现在包含：`image.png`、`corners.png`、`robot_frames.json`、`cloud.npz`、`sample.json`。

### 3.2 `scripts/solve_handeye_checkerboard.py`

- **新增 `observability()`**：给出 AX=XB 设计矩阵条件数。旋转部分用
  `R_A X_R = X_R R_B`（`R_A = rot(A_i⁻¹A_j)`、`R_B = rot(B_i B_j⁻¹)`）列堆叠成
  `M = kron(I, R_A) − kron(R_Bᵀ, I)`，报奇异值、`rank@1e-9`、`null_space_gap = σ₈/σ₉`、
  `condition_number`；平移部分用 `(I − R_A)t_X = …`，其条件数有限且有意义；
  另报**相对旋转轴各向同性** `min_over_max`（≈0 表示所有相对旋转共轴 ⇒ 退化）。
- **新增 `--holdout-ids`**：留出集可以用样本 id 显式钉死（默认仍是"最后 N 个"），
  使划分可复现、与排序无关；少于 5 个直接报错。

### 3.3 新增 `scripts/analyze_handeye_closure.py`（独立验收）

与求解器分离：求解器产出候选，本脚本**审判**候选。给定冻结 yaml，对每个接受样本重算
`base_from_target = base_from_tool0 · tool0_from_camera · camera_from_target`，报

- **固定棋盘格闭环**：板原点位置散布（RMS/max/xy span）、板姿态散布（整体 + 法向）、
- **54 个角点的世界坐标散布**（RMS/p95/max，逐角点最大），
- 重跑样本自带的门禁（重投影 px、静止性 mm/deg、角点数），
- **原始点云逐角点交叉校验**：用 K/D + 角点像素在 `cloud.npz` 的深度通道上取邻域中值，
  与 PnP 期望的角点 xyz 比对 —— **不经过手眼变换**，因此是独立于标定的一条几何证据。

### 3.4 新增 `scripts/handeye_pose_advisor.py` + `scripts/check_handeye_plan_observability.py`

采集期间机器人必须静止、且由现场用示教器点动（禁止电脑端流式 IK）。为让 26 个位姿不是盲点，
新增点动导航：把"距离/倾角/方位角/滚转"四个量 ↔ `camera_from_target` 双向映射，
输出**目标 TCP 位姿表**（示教器可读的 x y z rx ry rz）、覆盖率报告与"下一个空槽位"。

---

## 四、离线数值门禁（无相机、无机器人）

### 4.1 闭环分析脚本自检 — `outputs/handeye/closure-offline-selftest-20260918.json`

命令：`python3 scripts/analyze_handeye_closure.py --self-test`

**8/8 PASS**

| 用例 | 期望 | 结果 |
|---|---|---|
| 合成数据集闭环原点 RMS | < 1e-6 mm | ✅（解析构造 `A_i X B_i = C`） |
| 合成数据集角点世界散布 | < 1e-6 mm | ✅ |
| 合成数据集姿态散布 | < 1e-4° | ✅（1e-4 度是双精度经 SVD 平均后的噪声底） |
| 标定偏 2 mm 必须被检出 | > 1 mm | ✅ |
| 可观性指标能识别**分散**设计 | 轴各向同性 > 0.01 | ✅ |
| 可观性指标能识别**退化**设计 | 退化集指标更低 | ✅（纯平移 + 零旋转集被判为共轴） |
| `cloud.npz` 往返（合成针孔深度渲染） | 角点 RMS < 0.5 mm | ✅ |
| `cloud.npz` 审计字段齐全 | 8 个关键 key 齐备 | ✅ |

### 4.2 点动导航自检 — `handeye_pose_advisor.py --self-test`

**7/7 PASS**

| 用例 | 结果 |
|---|---|
| 球坐标往返 < 1e-6 | ✅ |
| **`solvePnP` 的 `camera_from_target` 必须把靶标放在相机前方（+z）且模长=距离** | ✅ |
| **流水线约定下的参数还原 < 1e-6** | ✅ |
| 计划 26 槽 | ✅ |
| 每主壳 8 个方位 | ✅ |
| 倾角随壳递增 | ✅ |
| 覆盖率匹配器能把按计划构造的数据集**满槽填满** | ✅ |

**这里抓到一个真 bug（本轮最有价值的代码修正）：** 前三项里的前两项是本轮**补加**的。
原先只有一个"往返 < 1e-6"自检，它**只验证自洽**——把平移语义整个反向也能通过。实际写出来的
`camera_from_target_from_spherical` 把 `transform[:3,3]` 当成"相机在靶标系的坐标"，而流水线里
（`solvePnP` 的 tvec）`camera_from_target[:3,3]` 的含义是**"靶标原点在相机系的坐标"**，两者相反。

- 影响面：**计划的绝对 TCP 位姿一直是正确的**（`base_from_target @ target_from_camera` 在数学上
  与约定无关，测试证实修复前后计划的 26 个 TCP 目标**逐位不变**）；错的是**覆盖率报告与 `--live`**
  这些把流水线 `camera_from_target` 直接喂回球坐标函数的地方——它会把一个真实样本读成
  `tilt 173.8°`（应为 28.0°），从而给出完全错误的"下一个空槽位"。
- 修法：函数按真实语义改名 `target_from_camera_from_spherical` / `spherical_from_target_from_camera`，
  所有持有流水线 `camera_from_target` 的调用点先取逆；并补上上面两条**钉住约定**（而非只验自洽）的自检。
- 验证：真实冒烟样本修复后读作 `dist 0.386 m / tilt 28.0° / azimuth 184.6°`（人工目测点位，合理）。

### 4.3 计划可观性门禁 — `outputs/handeye/plan-observability-gate.json`

命令：`python3 scripts/check_handeye_plan_observability.py --reference <参考样本>`

对每一种滚转模式，用参考样本预测出整套 26 个位姿，再跑求解器同款的可观性判据：

| 滚转模式 | rank | null_space_gap / cond | 轴各向同性 | 法兰最低 z | 不同滚转值 | 方位扇区 |
|---|---|---|---|---|---|---|
| design（设计滚转 ±25/±45°） | 8 | exact (floor) | **0.107** | **0.079 m** | 4 | [4,3,3,3,4,3,3,3] |
| clearance（取法兰最高的滚转） | 8 | exact (floor) | 0.032 | **0.255 m** | 3 | [4,3,3,3,4,3,3,3] |

`rank = 8` 正是手工眼齐次系统的良态值；`null_space_gap`/`cond` 显示 "exact (floor)" 是因为
合成数据无噪声、零空间在双精度下精确（不是病态）——工具会把这种情况显式标注为
`null_space_at_numerical_floor`，避免把"精确零空间"误读成天文数字的条件数。
对照组：09-17 的**真实**数据 `rank 9`、`gap 37.2`、`cond 89.7`、`σ₉/σ₁ = 1.1e-2`（远离噪声底），
说明这两类数字含义不同、工具能区分。

**决策：采用 clearance 模式。** 依据是实测而非偏好——09-17 那套**物理上成功采过**的 20 个位姿，
法兰高度实际范围是 **0.202–0.430 m**（§六）。design 模式会把法兰压到 0.079 m，比历史上任何一次
都低 12 cm，属真实避障风险；而它换来的轴各向同性提升（0.107 vs 0.032）不是"退化 vs 非退化"的
差别（两者都远离 0，且 8 方位 × 3 倾角的铺开本身已提供多轴激励）。

### 4.4 对 09-17 真实数据的回归（确认改动没破坏既有结论）

- `solve_handeye_checkerboard.py` → `outputs/handeye/regression-solution-20260918.json`：
  Park 留出 **2.642 mm / 1.051°**，最大 3.855 mm / 1.837°；Park-vs-Horaud **0.391 mm / 0.232°** ——
  与 `config/handeye_eye_in_hand_20260917.yaml` 里记载的数值**逐位一致**。
- `analyze_handeye_closure.py` → `outputs/handeye/regression-closure-20260918.json`：
  20 个接受样本，板原点散布 RMS 1.991 mm / max 3.352 mm，板 xy 跨度 3.92×5.02 mm，
  54 角点世界散布 RMS 1.981 mm / p95 2.916 / max 3.662 mm，姿态散布 RMS 0.832°
  —— 与文档记载的留出闭环 2.642 mm / 3.855 mm **同量级且方向一致**，指标互相印证。
- 09-17 的 AX=XB 设计矩阵：`null_space_gap` 37.2、`cond` 89.7、轴各向同性 0.217
  ⇒ 那套数据**并不退化**，2.6 mm 级残差应另有来源（本轮不做结论）。

---

## 五、真机冒烟测试（1 个样本，只读，不动机械臂）

命令：`python3 scripts/collect_handeye_sample.py --save-cloud --dataset outputs/handeye/smoketest-20260918.json`

| 量 | 值 |
|---|---|
| 样本 id | `20260918-112826-092467` |
| TCP（均值） | `(0.4670, -0.0537, 0.3753)` |
| 棋盘格 | **54/54** 内角点 |
| 重投影 RMS | **0.2484 px**（门限 0.5 px） |
| 采集期间运动 | **0.0383 mm / 0.0067°**（门限 0.5 mm / 0.2°） |
| UR 帧数 | 352 帧 / 2.825 s ≈ 125 Hz |
| 工作距离 | 0.386 m |
| `robot_frames.json` | 196 KB，全量帧已落盘 |
| `cloud.npz` | 7.0 MB；`finite_fraction` 0.708；15 个 key 齐备 |
| **真实点云逐角点校验** | 54/54 有邻域，**RMS 1.175 mm / p95 1.363 / max 1.409 mm** |

后者与交接文档记载的 09-17 结果（54/54 有效、XYZ RMS 0.692 mm、p95 1.197 mm、max 1.332 mm）
同量级，确认新落盘链路在真机上可用。

---

## 六、09-17 实测姿态分布与法兰高度（用于定新分布，也是本轮的"实测基准"）

20 个接受样本。距离 0.314–0.723 m、全程 54/54 角点、重投影 0.128–0.383 px（**全部**在 0.5 px 门限内）、
静止性 0.015–0.071 mm / 0.005–0.013°（余量极大）⇒ **采样余量不是瓶颈，姿态覆盖才是**。
倾角（相对板法向）10.8–63.4°，方位跨度 324.8°，但 8 个 45° 方位扇区里**有 2 个是空的**。

法兰高度（由记录 TCP z 与旧标定反算相机高度后得）：

| 量 | 范围 |
|---|---|
| TCP z | **0.202 – 0.430 m** |
| 相机 z | 0.155 – 0.587 m |
| 相机 z − TCP z | −0.188 – +0.282 m（随姿态变化很大，说明滚转/倾角组合对避障影响显著） |

⇒ 新计划的**法兰高度地板取 0.202 m**（历史实测可用的最低值），并据此选定 clearance 滚转模式。

---

## 七、采集计划

### 批次 A（参与求解 + 留出）：26 次采集

3 个距离壳 × 8 个方位扇区（0/45/…/315°，**填满 09-17 的空扇区**）+ 2 个定点重复。

| 壳 | 距离 | 倾角 | 设计滚转 | 样本数 |
|---|---|---|---|---|
| A1 | ≈0.35 m | 15° | +25° | 8 |
| A2 | ≈0.45 m | 30° | −25° | 8 |
| A3 | ≈0.58 m | 50° | ±45° 交替 | 8 |
| 重复 | A1/A2 各一 | 同前 | 同前 | 2（求解前由去重淘汰） |

实际滚转取 clearance 最优（实测 ≈188–192°），法兰高度 0.255–0.489 m 全部 ≥ 0.202 m 地板。

**划分**：先按 5 mm / 2° 去重，再用 `--holdout-ids` 显式钉死 **留出 6 个**（每壳 2 个）不参与求解，
训练 18–20 个。**求解**：Park 为主，Horaud + Tsai 交叉；报设计矩阵条件数、训练残差、留出残差、
每样本重投影。

### 批次 B（冻结 yaml 后，完全不参与拟合）：6 个全新位姿

新壳 ≈0.30 m 与 ≈0.65 m（09-17 的外推区），方位取批次 A 里最薄的角，倾角 25°/40°。

### 独立验收

1. 批次 B 冻结后样本：平移 ≤ 5 mm、旋转 ≤ 2°。
2. 固定棋盘格闭环：全部样本的板原点 / 姿态 / 54 角点世界散布。
3. 原始点云逐角点交叉校验（不经手眼变换）。
4. 交叉方法差异：Park vs Horaud/Tsai ≤ 1 mm / 0.5°。
5. 重投影 RMS ≤ 0.5 px。

### 物块中心测量验收（第 7 节）

≥3 个重新摆放位置各一次 `measure_cube_geometry.py --capture --save-cloud`，配独立真值
（钢板尺/卡尺实测 + 顶面/侧面交叉解算），报误差分布。**不复用** 09-17 的"人工目测纠正点"
（与任何单侧面重建都不自洽，残差 22.2 mm）。

---

## 八、当前状态与现场要求

**进行中：采集尚未开始。** 需要现场配合的事项：

1. **方格实长已实测确认（2026-09-18，现场）**：标定板为 **6 mm 边长方格**，已用尺量过并确认，
   与标称值一致。这补上了 09-17 遗留的"标称边长从未被独立验证"缺口。
   **待补**：量具型号/最小刻度（现场量完口述确认，量具信息未记录；如需写进正式报告请补一条）。
   0.006 m 作为 `square_size_m` 使用，与全部采集参数一致。
2. **示教器点动**：由你操作；采集期间机械臂必须静止（脚本门禁 ≤0.5 mm / ≤0.2°，超限丢样本重采）。
   目标位姿表见 `outputs/handeye/pose-plan-20260918.json`（`plan[].target_tcp_pose_m_deg`）。
3. **相机节点归属（现场实测结论）**：相机节点由**你的真实终端**持有（现场观测到
   `gnome-terminal → start_dashboard.sh → ros2 launch`，PID 16779，11:25:50 起）。
   我这边**不**再另起节点——同时两个实例会抢同一个相机。已把我先前起的那个退掉。
   我在客户端一侧只设 `FASTDDS_BUILTIN_TRANSPORTS=UDPv4`，实测可直接与你的节点通信
   （`/device_info` 正常应答）。这是沙箱绕行，**不需要**改你的启动方式。
4. 每个样本落盘后核对：角点 54/54、重投影 < 0.5 px、运动门限、`cloud.npz` 与 `robot_frames.json` 存在。

判据未达标 ⇒ `valid: false` 并把失败数值逐条写进 yaml；达标才写 `docs/`。

---

## 九、预飞检查清单（采集前最后一遍，全部已过）

| 项 | 结果 |
|---|---|
| `diagnose.py` / `read_ur_state.py` | 全绿；RUNNING / NORMAL |
| 相机单实例 + 我的 UDP 客户端可达 | ✅（人类终端节点 PID 16779） |
| 相机采集链路 | ✅ `validate_mecheye_capture.py` 通过 |
| 闭环分析离线门禁 | ✅ 8/8 |
| 点动导航离线门禁 | ✅ 7/7 |
| 计划可观性门禁 | ✅ rank 8、方位扇区铺满、法兰 ≥ 0.255 m |
| 物块测量离线门禁 | ✅ 6/6 |
| 09-17 真实数据回归 | ✅ Park 留出 2.642 mm / 1.051°、Park-vs-Horaud 0.391 mm / 0.232°，逐位一致 |
| 真机冒烟样本 | ✅ 54/54、重投影 0.2484 px、运动 0.0383 mm、点云角点 RMS 1.175 mm |
| 全部改动脚本 | ✅ `py_compile` 通过 |

---

## 十、能不能用脚本把机械臂直接开到目标位姿？（离线数值门禁层，只读）

问题来自现场："你不能直接控制移动到这里吗"。先按仓库规矩分清**禁的是什么**：

| 路径 | 状态 | 依据 |
|---|---|---|
| 电脑端 **流式 IK**（`servoj` 125 Hz 连续流） | **禁止** | `HANDOVER.md:46`、`README.md:38`；入口 `scripts/test_ik_move.py --execute` 已被硬禁用（脚本自己 `p.error("真机 IK 执行已禁用…")`），历史触发 `C153A0` 保护停 |
| 控制器**原生 `movel`**（URScript，端口 30002，控制器自己做 IK 与规划） | **允许，已有先例** | 09-17 视觉抓取记录明确写"机器人运动使用控制器原生 URScript `movel`，**没有运行禁用的流式 IK**"；09-18 位置抓放闭环也走这条；入口 `scripts/position_pick_place.py`、`scripts/ur_relative_movel.py` |

所以答案是：**可以，走 `movel` 这条**（不是被禁的那条）。但它属于"真机运动"，必须过
`离线数值门禁 → 单段低速真机 → 完整流程`（`movel` 路径不经过 ROS 轨迹控制器，
"官方假硬件"那一层针对的是 ROS 轨迹链路，不适用于 URScript 直发）。

### 10.1 新增 `scripts/check_move_plan.py`（只读，不打开 30002）

复用既有、已验证的模型与 IK：`ur_pose_ik.UR10IK`（pinocchio + `~/ur_learn/generated/ur10.urdf`）、
以及 `test_ik_move.py` 里那个被 FK 对控制器验证过的 `BASE_FROM_URDF_ROOT`
（即交接文档所述 base↔base_link 同位置、绕 Z 转 180°）。

门禁内容：

1. **FK 一致度**：实测 **0.002510 m / 0.003585 rad**（门禁 0.010 m / 0.020 rad）→ PASS。
   注意：这是**标称 URDF** 的一致度；交接文档里 0.017 mm 那条用的是工厂标定文件
   `config/ur10_factory_calibration.yaml`。2.5 mm / 0.21° 对"把相机摆到板前 0.35 m"完全够用
   （板宽 60 mm，容差是厘米级），但必须写明，不能当 0.017 mm 用。
2. **可达性与关节限位**：每个位姿 IK 残差、关节余量（2° 边界）、连续解之间的关节跳变。
3. **奇异度**：沿路径逐点算帧雅可比最小奇异值，与**当前位姿基线 0.2894** 比较。
4. **法兰高度地板 0.25 m**（沿用 `ur_relative_movel.py` 自己的硬门禁）。
5. **`movel` 是笛卡尔直线** ⇒ 单独可达的目标沿直线仍可能不可达：每段按 60 点密采样，
   逐点 IK 并用**上一点热启动**，并检查关节限位在**路径上**（不只是端点）是否越界。
6. 结构上取代"无碰撞证明"：**抬升 → 平移/变姿态 → 下降**，巡航高度 0.55 m 高于台面
   所有物体（板几毫米、物块 50 mm）。**这不是数值证明，是物理论证**，仍需人眼确认。

### 10.2 4 个试跑位姿的门禁结果

| slot | 结论 | 段序 | 关节余量最小 | 最小奇异值 | 法兰 z 最小 |
|---|---|---|---|---|---|
| 1 | **PASS** | reorient_first | 0.348 rad | 0.1029（基线 0.2894 的 36%） | 0.2552 m |
| 11 | **PASS** | reorient_first | 0.094 rad | 0.0940 | 0.3939 m |
| **16** | **FAIL** | 两种段序都不过 | **0.000 rad（顶到限位）** | — | — |
| 19 | **PASS** | reorient_first | 1.285 rad | 0.2848 | 0.4877 m |

**这是本轮最有实操价值的发现：** slot 16（A2 / 0.45 m / 30° / 方位 315°）的**目标姿态**
在关节限位下不可达——"原地变姿态"在第 51 个采样点就顶到限位；把段序换成"先平移到目标 x,y
再变姿态"仍不可达（第 43 点）。位姿本身位置没问题，卡的是**手腕构型**。

⇒ 说明 `clearance` 滚转模式（取法兰最高的滚转 ≈190°）虽然解决了台面避障，却会在某些方位把
手腕推到极限。**修法方向明确：滚转选取要同时过"法兰高度"和"IK 关节限位"两道判据**，
即在 `handeye_pose_advisor.choose_roll` 里加入 IK 可行性过滤，再重跑本门禁。

门禁同时暴露了首版实现的一个缺陷并已修：段失败后原实现把被污染的终解当下一段种子，
导致失败向后连锁；现在改为**失败即复位种子**并**自动试第二种段序**，因此上表里 slot 19
是在 slot 16 失败后独立评估的结果，真实可行。

### 10.3 收敛过程与最终结果（26/26 通过）

首轮全量门禁是 **25/26**（slot 17 失败）。逐条定位后按"改动越小越好"的顺序修：

| 措施 | 依据 | 效果 |
|---|---|---|
| **访问顺序改为关节空间最近邻** | slot 17 单独评估 PASS、紧跟 slot 16 却 FAIL ⇒ 可达性依赖前驱 | 修掉 slot 17；但又暴露 slot 1/8 |
| **失败位姿排队尾重试** | 同上，换前驱可能就通了 | slot 8 自动通过；slot 2、3 在最终版靠它通过 |
| **巡航高度备选搜索**（0.50/0.60/0.65 m） | 巡航高度是自由参数，只要高于台面所有物体 | 未解决 slot 1，但保留为通用救援手段 |
| **绕光轴滚转备选搜索**（±15°…180°） | 滚转是自由自由度，不改变看到板的哪一部分 | 救回 slot 9（−30°）、11（+30°）、23（+60°） |
| **A1 壳方位集整体旋转 22.5°** | 标定板没有"哪个方向算 0°"这回事，方位集整体旋转**完全保留** 8 等分覆盖与 3 距离壳 / 3 倾角级 | **修掉 slot 1 及其重复位姿 25** |

A1 壳另一条候选（改 0.40 m / 20° 或 0.38 m / 25°）中也有一条能过，但**会同时改动距离壳与倾角级**，
削弱设计；故弃用，取只旋转方位集的最小改动。

**最终结果：26/26 全部通过**（2 个靠换前驱重试、1 个靠绕光轴 +30°），
`outputs/vision/scripted-move-offline-gate-26.json`。

### 10.4 最终计划的设计合规性核对（`outputs/handeye/pose-plan-20260918.json`）

| 属性 | 设计目标 | 实测 |
|---|---|---|
| A1 主槽 | 8 个等分方位 | 8 个，方位 **22.5 / 67.5 / … / 337.5**（整体旋转 22.5°，等分保持） |
| A2 / A3 主槽 | 各 8 个等分方位 | 各 8 个，方位 0 / 45 / … / 315 |
| 重复位姿 | 2 个 | 2 个（A1@22.5°、A2@180°） |
| 距离壳 | 0.35 / 0.45 / 0.58 m | 一致 |
| 倾角级 | 15 / 30 / 50° | 一致 |
| 法兰高度 | ≥ 09-17 实测地板 0.202 m | **0.2553 – 0.4890 m**，无一个低于地板 |
| 观察侧检查 `cos(tilt)` | 必须为正（相机在板的观察侧） | **0.6428 – 0.9659**，逐位姿等于 cos 15/30/50°，全部为正 |
| IK 关节余量（位姿层） | ≥ 2° | **最小 0.313 rad（17.9°）** |
| 可见性 | 8 个方位扇区铺满 | [4,3,3,3,4,3,3,3]，铺满 |
| 设计矩阵 | rank 8（良态） | **rank 8** |

### 10.5 ⚠️ 当前阻塞：有线网卡失去载波，机器人/相机只能走 VPN 隧道

2026-09-18 约 12:0x 起，`scripts/diagnose.py` 的 29999 / 30001 / 30002 读取全部超时。
定位结果：

```
ip -brief addr        → enp0s31f6  DOWN        （此前 UP 192.168.1.10/24）
ip link show enp0s31f6 → <NO-CARRIER,BROADCAST,MULTICAST,UP>  state DOWN
/sys/class/net/enp0s31f6/carrier → 0
ip route get 192.168.1.3 → via 172.18.0.2 dev singbox_tun table 2022 src 172.18.0.1
```

即**有线网卡 no-carrier（网线脱落 / 对端断电）**，`192.168.1.0/24` 的直连路由随之消失，
到机器人（192.168.1.3）与相机（192.168.1.33）的流量被 sing-box 的策略路由
（table 2022，rule 9000–9010）接管走隧道。表现：

- `ping 192.168.1.3` 仍通；裸 TCP 连接 `30002/30003`、相机 `5577` 也能**建立**
  （源地址 `172.18.0.1`）；
- **但数据流不可靠**：`diagnose.py` 的状态读取全部超时，`ss` 里同时出现大量
  从 WiFi `10.83.46.182` 发出的 `SYN-SENT`。

⇒ 结论：**这轮剩下的真机阶段（采集、开位姿）被这条阻断，必须先恢复有线链路**
（插回网线 / 确认机器人侧供电与交换机），并确认 `ip -brief addr` 里
`enp0s31f6` 重新拿到 `192.168.1.10/24`、`ip route get 192.168.1.3` 指向
`dev enp0s31f6`。**未擅自改动路由或 VPN 配置**。

绕行做法：离线门禁不需要机器人，用**最后一次实测状态**（`--assume-q/--assume-tcp`）
照常跑完；门禁 JSON 里 `current.source` 明确标注为 assumed，不会与实测混淆。
最后一次实测状态：`q = [0.24515, -1.67440, -1.97697, -4.28024, 4.75112, -2.69310]`，
`tcp = [0.466994, -0.053723, 0.375271, 1.935066, -2.364650, -0.000338]`，
FK 一致度 0.002510 m / 0.003585 rad。

### 10.6 网络中断的真正原因（现场更正）

先前归因为"网线被碰掉"。现场更正：**是机械臂拉到了自己的线缆、受力触发保护停**
（线缆是相机/力传感器那束，随相机一起运动）。这条更正很重要，因为它把"偶发网络故障"
改判为**一个已发生的、由机械臂自身运动造成的硬件事件**。

⇒ 影响：原先"台面上只有 ≤50 mm 物体"的避障论证**不覆盖线缆**，必须单独处理。见 §十一。

---

## 十一、线缆绞紧诊断与计划改版（2026-09-18 下午）

### 11.1 真机首次执行（L2 + 部分位姿）

**L2 单段低速真机 —— PASS**（`outputs/vision/motion/run-20260918-124430.json`）：

| 指标 | 实测 | 门限 |
|---|---|---|
| Z 实际位移 | **49.8585 mm**（指令 50） | 误差 1.5 mm |
| 到位误差 | **0.143 mm** | 1.5 mm |
| 最大路径偏离 | **0.114 mm** | 8 mm |
| \|F\| 变化 | **0.91 N** | 25 N |
| 姿态变化 | ~2e-4 rad | — |

静止受力基线 \|F\| = 5.597 N。**注意**：若控制器负载未配置，该值应在 m·g ≈ 34 N 量级；
实测 5.6 N 说明**控制器侧负载配置大致正确**，看门狗这条通道可用。

**全量执行跑到第 2 个位姿失败**（`outputs/vision/motion/run-20260918-124642.json`）：
第 1 个位姿（slot 21）采集成功 —— 样本 `20260918-124651-924295`，**54/54 角点、
重投影 0.1335 px、位置差 0.0 mm、姿态差 0.01°**；slot 17 的 translate 段超时，
只走了 13/28.6 cm。

### 11.2 查出的执行器 bug：到位判据只查位置、不查姿态

**纯转动段的 TCP 线速度天然≈0**，所以每个 `reorient` 段都在 0.0–0.2 s 内被判"到位"
（实测姿态只变了 0.00009 rad），下一条 `movel` 在转动未完成时就发出，两条运动叠加。

修法：到位判据改为**位置 + 姿态 + 线速度 + 角速度四项同时满足**
（`POSITION_TOLERANCE_M=1.5 mm`、`ROTATION_TOLERANCE_RAD=0.006 rad`、
`SETTLE_SPEED=0.003 m/s`、`SETTLE_ANGULAR_SPEED=0.02 rad/s`），并加**停滞检测**。
`pose_error()` 已单元验证（同一姿态 / 纯平移 / 纯转 90° / 转 1.7 rad 四种情形全对）。

同时修正第二个不忠实之处：执行器原本按槽位号顺跑，而门禁验证的是**特定访问顺序**
（关节空间最近邻 + 逐槽救援滚转）。已改为**逐段重放门禁 JSON 里的段列表与顺序**，
执行器不再自行重算路径。

### 11.3 关键发现：恒定滚转会把腕关节拧死（线缆绞紧机制）

对门禁轨迹逐段求 IK 并统计**腕关节 J6 的真实转角**：

| 方案 | J6 净变化 | J6 累计行程 | J6 范围跨度 | 最大单段 |
|---|---|---|---|---|
| **原计划（26 槽全部滚转 190°）** | −144.3° | **2140.3°** | 315.5°（**顶到 −360° 限位**） | **191.6°** |
| 360° 绝对锚定 J6 | +296.4° | 957.5° | 405.1° | 95.1° |
| **180° 半圈 + 绝对锚定** | +296.4° | 983.6° | **358.3°** | **72.7°** |

⇒ **原计划会把腕关节累计拧 6 圈、并顶到 J6 硬件限位**，这正是勒紧相机线缆的机制，
与现场那次"机械臂拉到自己线缆受力触发保护停"吻合。

改版措施与效果：

1. **滚转目标从"法兰最高"改为"腕部连续"**（`--roll-objective wrist`），
   并以**绝对锚定**（所有位姿的 J6 贴近起始 J6）而非增量锚定——增量锚定是顺序相关的，
   而滚转优化顺序与门禁执行顺序不一致，收益会被抵消（实测净绞紧仍 +222°）。
   滚动集合由恒定 {190°} 变为 95–220° 散开。
2. **法兰下限提到 0.25 m**（沿用 `ur_relative_movel.py` 自身的硬门禁），
   防止"为连续性牺牲避障"：实测法兰 0.2502–0.4853 m，无一个低于 0.25 m。
3. **方位跨度收到 180°**（`--azimuth-span-deg 180`）：仍是 8 个不同方向，满足
   "朝向至少 3 个方向"的要求，但单段最大腕转从 95.1° 降到 **72.7°**、跨度降到 358.3°。

结果：累计行程 −55%、最大单段 −62%、**不再顶 J6 限位**。
**但净绞紧仍约 +296°**，即"把腕子拧大半圈"这件事在模型层面没有被消除。

### 11.4 必须说清的模型局限

上述 J6 数字是**标称 URDF 的 IK 推算**，不是控制器实际关节角：同一个笛卡尔位姿有多个
IK 解，控制器按自己的准则选分支。所以这些数字只能作**相对比较**，不能当实测。

⇒ 因此给执行器加了**实际关节角记录**（`run_move_plan.py` 的 `actual_wrist` 块：
从 30003 的 `q_actual` 直接读 J6 的起点/终点/净变化/累计行程/跨度）。
**真实结论必须来自实跑数据**，做法是分段执行（`--first-slots N` 取访问顺序的**前缀**，
不能用 `--slots` 任意子集，否则起点与门禁链不符——执行器已加该校验并实测拒绝过一次）。

### 11.5 当前状态与阻塞

- 已采样本 **1 个**（`outputs/handeye/eye-in-hand-20260918.json`），54/54、重投影 0.1335 px。
- 计划与门禁产物：`pose-plan-20260918.json`（原）、`pose-plan-wrist2-20260918.json`（360° 绝对锚定）、
  `pose-plan-half-20260918.json`（**180° 半圈，当前首选**）；对应门禁
  `scripted-move-offline-gate-26.json`、`gate-wrist2.json`、`gate-half.json`，**均 26/26 PASS**。
- 执行器 `scripts/run_move_plan.py` 已具备：门禁一致性校验（漂移 + 首段起点）、
  **忠实重放**、位置+姿态到位判据、看门狗（直线不变量 8 mm + \|F\| 变化 25 N → `stopj`）、
  自动采集、前缀分段、实际 J6 记录。
- **阻塞在现场决策**：线缆绞紧机制已查明并缓解，但模型上仍存在约 296° 净绞紧；
  是否继续全量采集、还是先把线缆走线改造好，需现场判断。
- 现场同时要测其他控制程序 ⇒ 本轮运动工作暂停；**30002 未占用、本 agent 无运动进程**。
  机械臂停在 `(0.5304, -0.1147, 0.5499)`（半空，安全）。门外程序一旦移动机械臂，
  本轮的位姿门禁即失效，恢复时需从当前位姿重跑 `check_move_plan.py`（离线 ~3 min）。

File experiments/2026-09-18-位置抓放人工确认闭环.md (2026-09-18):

# 2026-09-18 · 位置抓放（人工确认夹持）

## 结论

完成一次位置式抓放闭环：取物点闭合后，Robotiq 返回 `POS=229 / OBJ=3 / FLT=0`，
脚本按机械反馈停止。用户现场确认物块实际被夹住后，继续完成抬升、水平搬运、下降、
张开释放和抬升离开。该结果证明位置运动链和夹爪动作链可执行，但不证明 `OBJ=3`
可以替代 `OBJ=2`，也不构成自动抓取验收。

## 数值证据

| 阶段 | 目标/结果 | 位置误差 |
|---|---|---:|
| 取物点抬升 20 mm | `z=0.2960 m` | `0.148 mm` |
| 安全高度再抬升 30 mm | `z=0.3260 m` | `0.098 mm` |
| 水平到放置点上方 | `x=0.6723, y=0.0368 m` | 最终确认到位 |
| 下降到放置点 | `z=0.2761 m` | `0.207 mm` |
| 放置后抬升 50 mm | `z=0.3258 m` | `0.329 mm` |

运动证据 JSON：

- `outputs/vision/gripper-lift-check-20260918.json`
- `outputs/vision/gripper-hover-check-20260918.json`
- `outputs/vision/gripper-place-hover-20260918.json`
- `outputs/vision/gripper-place-descend-20260918.json`
- `outputs/vision/gripper-place-lift-20260918.json`

全程未使用 ATI、重力补偿或力控；使用控制器原生 `movel` 和 Robotiq ASCII。

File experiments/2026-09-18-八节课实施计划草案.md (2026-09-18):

# 机械臂工程实践 8 节课 · 实施计划（草案 v1）

范围：本轮实施**第 1–6 节**。第 7、8 节延后（用户 2026-09-18 决定）。
不采购新硬件。第 4 节以闭合并拢的**左夹爪指尖代替笔尖**做 TCP 标定。

> 本草案的每一条结论都标注了依据；依赖外部检索的方法选择标 `【待检索确认】`。

---

## 1. 现状盘点（已核实）

| 课 | 现有资产 | 主要缺口 |
|---|---|---|
| 1 整体认识 | `docs/01` 有拓扑、端口全表（含实测频率）、示教器开机流程 | 缺系统组成图与设备铭牌/序列号清单 |
| 2 示教器运动 | 30003/30013 状态回读实测 125 Hz（`probe_ur_realtime.py`） | 缺示教器操作流程文档 + 教学版状态读取脚本 |
| 3 ROS 控制运动 | 官方 `ur_robot_driver 2.14.0` 可启动；抓放闭环曾通过 | **负载未验证 → 运动被锁**；无安全的最小运动入口 |
| 4 关节标定 | 工厂运动学已提取（FK 对控制器偏差 0.017 mm）；`calibrate_fingertip_tcp.py`（只读、带静止门禁与留出验证）；`ur_relative_movel.py`（带门禁的安全相对移动） | TCP 未现场采集；无 100.5 mm 直线精度实验 |
| 5 机器人感知 | 手眼标定已独立验收（Park 解留出 RMS 2.642 mm/1.051°，冻结后新样本 2.614 mm/0.401°）；ATI 原始数据 200 Hz 稳定 | **重力补偿全部 `valid:false`**；**时延/时间同步零工作** |
| 6 视觉抓取 | 点云-图像逐角点 RMS 0.692 mm；手眼已验收 | **物体中心定位 35.84 mm 误差未通过** |
| 7 转盘动态抓取 | 仅 `speedl`/`servoj` 基础已验证 | 全空白；且相机采集速度存疑（见 §5） |
| 8 毛笔字机器人 | 数字孪生、运动学 | 全空白，依赖第 4 节 TCP 与第 5 节力控 |

依赖链：`3 → 4 → 5 → 6`，`4 + 5 → 8`。

---

## 2. 三个阻塞与解决顺序

现在真机运动整体被禁用，根因有三个，彼此耦合：

- **阻塞 A · 负载（payload/CoG）未独立测量** → 影响第 3、4、6 节全部真机运动
- **阻塞 B · 重力补偿全部 `valid: false`** → 影响第 5 节力觉、第 8 节力控
- **阻塞 C · 时延与时间同步完全没做** → 全库检索 `延迟|时延|latency|时间同步|时间戳对齐` 零命中；而第 5 节明确要求"特别注意数据时间上的延迟"

### 关键认识：A 与 B 是同一套物理量

工具链为 `法兰 → ATI 力传感器 → [偏心相机] + [正装夹爪]`。重力补偿要辨识的
（末端质量 m、重心 r）与 UR `set_payload` 需要的（质量、重心）**是同一组参数**。
一次规范的静力学标定应同时解开 A 和 B，不应做成两件事。

---

## 3. 必须先做的三项前置实验（P0）

### P0-0 · 第 6 节 35.84 mm 的算术快查（30 分钟，最高性价比）

**发现**：50 mm 立方体半边长 25 mm，`√(25²+25²) = 35.36 mm`，与实测 **35.84 mm** 只差
0.48 mm —— 正好等于你们标定/点云的亚毫米残差量级。

若真的"只用**单个**可见侧面 + 沿其法向偏半边长"，期望误差应是 **25 mm（单轴）**，
不是 35.36 mm。所以高度提示：**候选中心在水平两个轴上各偏了一个半边长**
（可见区域实际是**两个相邻竖直侧面的并集**的质心，或半边长偏移被施加到了两个轴）。
这属于**几何方案/定义错误，不是精度不够** —— 先验证这条，比调任何标定参数都值。

**怎么做**：打印"视觉候选中心 − 人工确认抓取中心"的**差向量**（不是只报模长 35.84 mm），
检查是否 ≈ `(±25, ±25, 0)` 或 `(0, 0, ±25)`。差向量的方向直接指出错在哪一步。

**正确算法（单视角只有 1–2 个侧面时）**：
聚类 → RANSAC 取最大平面 → 判定是否**顶面** → 顶面法向 `n̂` + 内点 → 投影到平面 →
2D 凸包 → **最小面积外接矩形**（rotating calipers）→ 得边长 `(a,b)` 与矩形中心 `c_foot` →
**验收 `(a,b) ≈ (50,50) mm ± 2 mm` 且覆盖率 > 85%，否则判退化拒识** →
**中心 = `c_foot − (h/2)·n̂`**。侧面**只用于约束 yaw / 交叉验证**，不得单独推中心。

---

## 2.5 已排除的嫌疑（不要再花时间查）

| 嫌疑 | 结论 | 依据 |
|---|---|---|
| 点云单位 mm/m 混用（1000× 错误） | **排除**：实测 `xyz_median` ≈ 0.259，与工作距离 0.3–0.6 m 同量级 → 单位是米 | `outputs/camera/capture-validation-20260914-154850.json` |
| 米制尺度完全未验证 | **部分已验**：棋盘格格长 6 mm 就是独立长度基准，"逐角点 RMS 0.692 mm"已把尺度误差约束到 ~1.4%。**仍缺**全视场（数百 mm 量程）的独立长度基准验证 | 同上 + 手眼标定记录 |
| 用了非官方 ROS 驱动（因英文文档话题表无 `color_image`） | **排除**：那是**官方英文页笔误**（重复列 `stereo_color_image_left`、漏掉 `color_image`）。中文页与源码均确认 `/mechmind/color_image` 是官方话题 | 中/英文 2.5.0 `api/ros2.html` 对比；`MechMindCamera.cpp` `create_publisher("/mechmind/color_image")` |
| `base` 与 `base_link` 相差 1.182 m（平移） | **改为**：UR 官方《Robot Frames》明确两者**位置相同、仅绕 Z 轴旋转 180°**。180° yaw 使半径 r 处的点位移 **2r**，r≈0.591 m → 正好 1.182 m。**这是"绕基座旋转"效应，不是变换里的平移分量** | UR 官方文档原文 "but is rotated by 180 degrees around the Z-axis" |

**建议现场一条命令确认**：
```bash
ros2 run tf2_ros tf2_echo base base_link     # 期望：平移≈0、yaw=180°
```

---

### P0-1 · 力标定的 2 倍质量矛盾 ★最高优先

**发现**：仓库所有独立拟合的末端质量高度一致地收敛到 **3.20–3.29 kg**
（3.217 / 3.2223 / 3.2222 / 3.2119 / 3.2025 / 3.2947 / 3.2257 kg，横跨 6 次不同采集批次）；
但 2026-09-10 的**单姿态** `|F|/g` 独立反推为 **6.56 kg**（`F=(0.39,11.15,63.36) N`，`|F|=64.4 N`）。

两者相差 **2.03 倍**，且拟合结果极度可重复 —— 这说明误差是**系统性的**，
不是噪声、不是姿态覆盖不足、也不是条件数问题（条件数 8.2–9.1 一直在门限内，
残差却有 2.0–15.4 N）。

**为什么这是第一优先**：一个 2 倍量级的系统性错误会让此后所有数字失去意义 ——
包括"力 RMS ≤ 1.0 N"这类验收门限本身、任何力控增益、以及 UR 负载参数。
这也能解释为什么"每加一个新独立姿态就出现 2 N 反例"：模型尺度不对，
在某些姿态方向上的偏差必然放大。

**怎么做**（只读，不动机械臂，约 1 小时）：
1. 在**至少 3 个差异大的静态姿态**记录 `/ft_sensor/wrench_raw`，每个姿态等待静止，
   计算 `|F_raw|`。若无外力，`|F_raw|` 应**与姿态无关**且等于 `m·g`。
   - 若三个姿态的 `|F_raw|` 都 ≈ 6.5·g → 拟合设定错误（旋转约定/坐标系）
   - 若都 ≈ 3.2·g → 2026-09-10 那次测量被高估 2 倍
2. 核对 `scripts/ati_netft_node.py` 中的换算常数：源码里是**硬编码默认值**
   `DEFAULT_COUNTS_PER_FORCE = 1_000_000.0` 与 `DEFAULT_COUNTS_PER_TORQUE = 1_000_000.0`。
   必须与**该传感器的实际标定文件/量程**一致，否则所有用力值表示的结论
   （含 1.0 N / 0.1 N·m 门限）单位都是错的。
3. 复核 ATI 硬件 Bias（应为六路全零）与软件 Tare 的取值姿态 —— 仓库历史中
   记录过一次"错误写入 Bias 导致**读数翻倍**"的事故，2 倍现象在本系统上确实出现过。

**判据**：三个以上姿态的 `|F_raw|/g` 一致，且与多姿态拟合质量一致（相对偏差 < 5%）。
**产出**：`outputs/ft_calibration/mass-scale-diagnosis-<日期>.json` + 结论写入 `docs/12`。
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

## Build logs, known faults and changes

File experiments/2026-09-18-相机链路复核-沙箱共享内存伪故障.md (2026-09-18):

# 2026-09-18 相机采集链路复核：不是链路故障，是 DSH 沙箱私有 /dev/shm 打断 FastDDS 共享内存传输

## 结论摘要

1. **相机采集链路本身完全正常**。带 `FASTDDS_BUILTIN_TRANSPORTS=UDPv4` 后：
   `/device_info` 正常应答、`scripts/validate_mecheye_capture.py` 全流程通过、
   `scripts/check_handeye_checkerboard.py` 能取图并落盘。
2. **2026-09-18 入口可用性审计 §3.2 的"相机服务无响应"是伪故障**：根因是执行该命令的
   DSH 沙箱把 `/dev/shm` 做成**每次 bash 调用私有的 tmpfs**，Fast DDS 进程间共享内存
   传输因此必然失效——发现（UDP 多播）仍正常，所以话题/服务都能被列出来，但**用户数据
   永远送不到**。两个进程即使在同一个沙箱内也互相收不到消息。
3. 因此 §3.2 里"`ros2 service call /device_info` 40 s 无响应"的现象，**不能**归因于相机、
   SDK、IP 直连或 ROS 服务机制；它与 `/var/log` 只读也**无关**（下一条）。
4. `/var/log` 只读确实会发生（SDK 打印 `Logger: Error: No write permission for directory /var/log/`），
   但它**不阻塞**任何功能：本记录中所有成功采集都发生在 `/var/log` 仍只读的沙箱里。

## 判别过程（每步都可复现）

### 第 1 步：先按原样复现现象

沙箱内 `/var/log` 只读（与 §3.2 同条件）：

```bash
touch /var/log/.dsh_test    # → Read-only file system
```

按文档流程启动相机（沙箱内，未设任何 Fast DDS 变量）：

```bash
ros2 launch ~/colcon_ws/src/mecheye_ros2_interface/launch/start_camera_ur10.py
```

启动日志与 §3.2 完全一致：`No write permission for directory /var/log/`、
`Failed to obtain the IP address of the computer Ethernet port...`（多网卡已知警告）、
`按 IP 直连相机成功: 192.168.1.33 (固件 2.5.0)`、型号 `Mech-Eye PRO XS`、
SN `RAM35238A3020004`。`ss -tnp` 显示 `192.168.1.10:41776 → 192.168.1.33:5577 ESTAB`。

复现超时：

| 调用 | 结果 |
|---|---|
| `ros2 service call /device_info ... "{}"` | 30 s 无响应 |
| `ros2 service call /get_int_parameter ...` | 25 s 无响应 |
| `python3 scripts/validate_mecheye_capture.py` | `TimeoutError: image capture/message timeout after 20.0s` |

### 第 2 步：分离"节点卡死"与"传输不通"

决定性观察：**连原生 rclpy 服务也无响应**：

```bash
ros2 service call /mechmind_camera_publisher_service/describe_parameters \
  rcl_interfaces/srv/DescribeParameters "{names: ['save_file']}"   # 20 s 无响应
```

`describe_parameters` 由 rclpy 内部实现、完全不碰 SDK。它可以排除"SDK 采集卡住"，
但也还不能排除"沙箱"。进程侧取证：相机进程存活、25 线程、CPU 0.2%、`wchan=0`
（睡眠在用户态，不是在内核等待），`MultiThreadedExecutor` 本应让某个回调阻塞时其它
回调仍能被服务——**却一个都不响应**。

### 第 3 步：在沙箱内自建最小服务做对照（关键一步）

在**同一个沙箱**里起一个 trivial 的 `std_srvs/Trigger` 服务提供者，另一个 bash 调用做客户端：

```python
# 提供者：只 create_service + spin，不碰任何硬件
print('wait_for_service ->', c.wait_for_service(timeout_sec=15.0))   # → True，0.0 s
# 调用后 10 s 内 future 始终未完成
# 同一对进程间的 std_msgs/String 话题：收到 0 条
```

⇒ **发现正常、数据不达**，而且这与相机毫无关系：连两个纯 Python 节点之间也这样。
这把根因从"相机/SDK/服务机制"彻底移到"沙箱的进程间传输"。

### 第 4 步：定位到 /dev/shm

```bash
grep shm /proc/mounts        # tmpfs /dev/shm tmpfs ro,nosuid,nodev,inode64 0 0
echo x > /dev/shm/dsh_probe.txt   # 本次调用内可写、可读
ls /dev/shm/dsh_probe.txt         # 下一次 bash 调用：No such file or directory
```

⇒ `/dev/shm` 在沙箱内是**每次调用重新挂载的私有 tmpfs**。Fast DDS 在同一主机上默认优先
用共享内存传输（builtin transport `SHM`），它靠 `/dev/shm` 里的段名匹配；两个持有**不同
`/dev/shm`** 的进程会匹配上名字却共享不到内存，于是建立不了数据通道，而基于 UDP 多播的
发现（discovery）照常工作。这精确解释了"服务列得出来、`wait_for_service` 为 True、
调用却永不返回"。

### 第 5 步：绕过并验证

把 Fast DDS 的传输限制为 UDP，禁用 SHM：

```bash
export FASTDDS_BUILTIN_TRANSPORTS=UDPv4
```

同一对最小服务/话题立刻正常：

| 量 | 禁用 SHM 前 | 禁用 SHM 后 |
|---|---|---|
| service future 完成 | False（10 s 超时） | **True**（`success=True, message='OK'`） |
| 收到话题消息数 | 0 | **24** |

相机侧（提供者与客户端都设该变量，`/var/log` 仍只读）：

| 调用 | 结果 |
|---|---|
| `ros2 service call /device_info` | 应答：`model='Mech-Eye PRO XS'`, `serial_number='RAM35238A3020004'`, `firmware_version='2.5.0'`, `ip_address='192.168.1.33'` |
| `python3 scripts/validate_mecheye_capture.py` | 通过，落盘 `outputs/camera/capture-validation-20260918-111955.json` |
| 点云 | `points=1310720`，`finite_fraction=0.661`，`xyz_min/max` 量级 0.24–1.23 m（米） |
| 颜色 | `bgr_identical_fraction = 1.0` ⇒ 再次确认单色（PRO XS 硬件规格） |
| `python3 scripts/check_handeye_checkerboard.py --output-dir outputs/handeye/recon-20260918` | 取图成功，`detected=False`（当前位姿看不到棋盘格，见下） |

## 对现场操作的要求

- 在 DSH 沙箱里跑**任何** ROS 2 话题/服务通信（相机节点、采集脚本、求解无关）都必须：
  ```bash
  export FASTDDS_BUILTIN_TRANSPORTS=UDPv4
  ```
  发起端与响应端**都**设，最省事。
- 这是**沙箱绕行**，不是仓库缺陷，也不是需要修的东西：普通终端（非 bwrap）里
  `/dev/shm` 是正常的，文档里原有的启动流程照旧有效。
- 反过来也成立：**以后在沙箱里遇到"ROS 服务/话题无响应"，先怀疑这条**，
  `export FASTDDS_BUILTIN_TRANSPORTS=UDPv4` 是最便宜的判别实验（10 秒出结论）。
- `/var/log` 只读（`Logger: Error: No write permission for directory /var/log/`）
  **不影响**任何功能，不必为它去改权限。

## 顺带确认的现场状态（2026-09-18 11:14–11:20，全部只读）

| 检查 | 结果 |
|---|---|
| `python3 scripts/diagnose.py` | 网络/29999/30001/30002/63352 全 OK；`robotmode RUNNING`、`safetystatus NORMAL` |
| `python3 scripts/read_ur_state.py` | `robotmode RUNNING`、`safetystatus NORMAL`、`programState STOPPED`；TCP `(0.647433, -0.268464, 0.326105)` |
| `python3 scripts/check_current_docs.py` | `Current-doc check passed: 18 Markdown files scanned.` |
| 当前位姿能否看到棋盘格 | **看不到**（`check_handeye_checkerboard.py` → `detected=False`, 0/54 角点）⇒ 采集前必须由现场用示教器把臂点动到同时可见棋盘格与物块的位姿 |
| `python3 scripts/test_measure_cube_geometry.py` | 离线门禁 **6/6 PASS**（含"掠射视角必须拒识"） |

注意：本次 TCP Z 为 `0.326105 m`，与交接记录里的 `≈0.276 m` 不同（机械臂已被移动过），
但这只是记录差异，不构成任何结论。

## 与 09-17 成功标定的关系

09-17 的手眼标定在**普通终端**里完成（当时相机链路是通的），与本记录不矛盾：
本记录只否证"09-18 相机链路坏了"这一判断，不改动任何 09-17 的标定数值。
09-17 标定的真实问题仍是**棋盘格已被移动**（绝对坐标失效）+ **未存原始点云**。

## 复现命令

```bash
cd ~/UR10
touch /var/log/.dsh_test                       # 期望 Read-only file system（沙箱特征）
export FASTDDS_BUILTIN_TRANSPORTS=UDPv4        # 关键绕行

# 终端 A：相机
source /opt/ros/humble/setup.bash && source ~/colcon_ws/install/setup.bash
ros2 launch ~/colcon_ws/src/mecheye_ros2_interface/launch/start_camera_ur10.py

# 终端 B：验证
source /opt/ros/humble/setup.bash && source ~/colcon_ws/install/setup.bash
python3 scripts/validate_mecheye_capture.py
```

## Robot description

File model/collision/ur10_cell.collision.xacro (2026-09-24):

<?xml version="1.0"?>
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
<robot xmlns:xacro="http://wiki.ros.org/xacro" name="ur10_digital_twin">
  <xacro:arg name="tf_prefix" default="twin_"/>
  <xacro:arg name="ur_type" default="ur10"/>
  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
  <xacro:arg name="tool_yaw" default="0"/>
  <xacro:property name="tool_yaw" value="$(arg tool_yaw)"/>

  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
  <xacro:property name="FT_D" value="0.050"/>     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
  <xacro:property name="FT_R" value="0.063"/>     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
  <xacro:property name="PLATE_D" value="0.033"/>     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
  <xacro:property name="GRIP_D" value="0.0759"/>    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
  <xacro:property name="GRIP_W" value="0.1471"/>    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
  <xacro:property name="FING_L" value="0.089"/>     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
  <xacro:property name="CAM_X" value="0.080"/>     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
  <xacro:property name="CAM_Y" value="-0.0474"/>   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
  <xacro:property name="CAM_Z" value="-0.0279"/>   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

  <xacro:include filename="$(find ur_description)/urdf/ur_macro.xacro"/>

  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

  <link name="world"/>
  <xacro:ur_robot
      name="ur10"
      tf_prefix="$(arg tf_prefix)"
      parent="world"
      joint_limits_parameters_file="$(find ur_description)/config/$(arg ur_type)/joint_limits.yaml"
      kinematics_parameters_file="$(find ur_description)/config/$(arg ur_type)/default_kinematics.yaml"
      physical_parameters_file="$(find ur_description)/config/$(arg ur_type)/physical_parameters.yaml"
      visual_parameters_file="$(find ur_description)/config/$(arg ur_type)/visual_parameters.yaml"
      safety_limits="false"
      safety_pos_margin="0.15"
      safety_k_position="20"
      force_abs_paths="false">
    <origin xyz="0 0 0" rpy="0 0 0"/>
  </xacro:ur_robot>

  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
  <link name="$(arg tf_prefix)ft_mount_plate">
    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
  </link>
  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
  <joint name="$(arg tf_prefix)tool0_to_ft_mount" type="fixed">
    <parent link="$(arg tf_prefix)tool0"/>
    <child link="$(arg tf_prefix)ft_mount_plate"/>
    <origin xyz="0 0 0" rpy="0 0 ${tool_yaw}"/>
  </joint>

  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
  <link name="$(arg tf_prefix)ati_sensor">
    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
  </link>
  <joint name="$(arg tf_prefix)ft_mount_to_ati" type="fixed">
    <parent link="$(arg tf_prefix)ft_mount_plate"/>
    <child link="$(arg tf_prefix)ati_sensor"/>
    <origin xyz="0 0 ${PLATE_D}" rpy="0 0 0"/>
  </joint>

  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
  <link name="$(arg tf_prefix)gripper_coupling">
    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
  </link>
  <joint name="$(arg tf_prefix)ati_to_coupling" type="fixed">
    <parent link="$(arg tf_prefix)ati_sensor"/>
    <child link="$(arg tf_prefix)gripper_coupling"/>
    <origin xyz="0 0 ${PLATE_D + FT_D}" rpy="0 0 0"/>
  </joint>

  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
  <link name="$(arg tf_prefix)gripper_base">
    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
  </link>
  <joint name="$(arg tf_prefix)coupling_to_gripper" type="fixed">
    <parent link="$(arg tf_prefix)gripper_coupling"/>
    <child link="$(arg tf_prefix)gripper_base"/>
    <origin xyz="0 0 ${2*PLATE_D + FT_D}" rpy="0 0 0"/>
  </joint>

  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
  <link name="$(arg tf_prefix)left_finger">
    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
  </link>
  <joint name="$(arg tf_prefix)left_finger_joint" type="prismatic">
    <parent link="$(arg tf_prefix)gripper_base"/>
    <child link="$(arg tf_prefix)left_finger"/>
    <origin xyz="0.0313 0 ${2*PLATE_D + FT_D + GRIP_D}" rpy="0 0 0"/>
    <axis xyz="1 0 0"/>
    <limit lower="0" upper="0.0425" effort="100" velocity="0.15"/>
  </joint>

  <link name="$(arg tf_prefix)right_finger">
    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
  </link>
  <joint name="$(arg tf_prefix)right_finger_joint" type="prismatic">
    <parent link="$(arg tf_prefix)gripper_base"/>
    <child link="$(arg tf_prefix)right_finger"/>
    <origin xyz="-0.0313 0 ${2*PLATE_D + FT_D + GRIP_D}" rpy="0 0 0"/>
    <axis xyz="-1 0 0"/>
    <limit lower="0" upper="0.0425" effort="100" velocity="0.15"/>
  </joint>

  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
  <link name="$(arg tf_prefix)camera_link">
    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
  </link>
  <joint name="$(arg tf_prefix)camera_mount_joint" type="fixed">
    <parent link="$(arg tf_prefix)ati_sensor"/>
    <child link="$(arg tf_prefix)camera_link"/>
    <origin xyz="0 0 0" rpy="0 0 0"/>
  </joint>
</robot>

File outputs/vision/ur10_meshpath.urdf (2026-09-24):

<?xml version="1.0" ?>
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
<robot name="ur">
  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
  <link name="world"/>
  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
  <link name="base_link"/>
  <link name="base_link_inertia">
    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
    <inertial>
      <mass value="4.0"/>
      <origin rpy="0 0 0" xyz="0 0 0"/>
      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
    </inertial>
  </link>
  <link name="shoulder_link">
    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
    <inertial>
      <mass value="7.1"/>
      <origin rpy="1.570796326794897 0 0" xyz="0.021 -0.027 0.0"/>
      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
    </inertial>
  </link>
  <link name="upper_arm_link">
    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
    <inertial>
      <mass value="12.7"/>
      <origin rpy="0 0 0" xyz="-0.232 0.0 0.158"/>
      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
    </inertial>
  </link>
  <link name="forearm_link">
    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
    <inertial>
      <mass value="4.27"/>
      <origin rpy="0 0 0" xyz="-0.3323 0.0 0.068"/>
      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
    </inertial>
  </link>
  <link name="wrist_1_link">
    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
    <inertial>
      <mass value="2.0"/>
      <origin rpy="1.570796326794897 0 0" xyz="0.0 -0.018 0.007"/>
      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
    </inertial>
  </link>
  <link name="wrist_2_link">
    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
    <inertial>
      <mass value="2.0"/>
      <origin rpy="-1.570796326794897 0 0" xyz="0.0 0.018 -0.007"/>
      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
    </inertial>
  </link>
  <link name="wrist_3_link">
    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
    <inertial>
      <mass value="0.365"/>
      <origin rpy="0 0 0" xyz="0.0 0 -0.026"/>
      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
    </inertial>
  </link>
  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
  <joint name="base_joint" type="fixed">
    <origin rpy="0 0 0" xyz="0 0 0"/>
    <parent link="world"/>
    <child link="base_link"/>
  </joint>
  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
  <joint name="base_link-base_link_inertia" type="fixed">
    <parent link="base_link"/>
    <child link="base_link_inertia"/>
    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
    <origin rpy="0 0 3.141592653589793" xyz="0 0 0"/>
  </joint>
  <joint name="shoulder_pan_joint" type="revolute">
    <parent link="base_link_inertia"/>
    <child link="shoulder_link"/>
    <origin rpy="0 0 0" xyz="0 0 0.1273"/>
    <axis xyz="0 0 1"/>
    <limit effort="330.0" lower="-6.283185307179586" upper="6.283185307179586" velocity="2.0943951023931953"/>
    <dynamics damping="0" friction="0"/>
  </joint>
  <joint name="shoulder_lift_joint" type="revolute">
    <parent link="shoulder_link"/>
    <child link="upper_arm_link"/>
    <origin rpy="1.570796327 0 0" xyz="0 0 0"/>
    <axis xyz="0 0 1"/>
    <limit effort="330.0" lower="-6.283185307179586" upper="6.283185307179586" velocity="2.0943951023931953"/>
    <dynamics damping="0" friction="0"/>
  </joint>
  <joint name="elbow_joint" type="revolute">
    <parent link="upper_arm_link"/>
    <child link="forearm_link"/>
    <origin rpy="0 0 0" xyz="-0.612 0 0"/>
    <axis xyz="0 0 1"/>
    <limit effort="150.0" lower="-3.141592653589793" upper="3.141592653589793" velocity="3.141592653589793"/>
    <dynamics damping="0" friction="0"/>
  </joint>
  <joint name="wrist_1_joint" type="revolute">
    <parent link="forearm_link"/>
    <child link="wrist_1_link"/>
    <origin rpy="0 0 0" xyz="-0.5723 0 0.163941"/>
    <axis xyz="0 0 1"/>
    <limit effort="56.0" lower="-6.283185307179586" upper="6.283185307179586" velocity="3.141592653589793"/>
    <dynamics damping="0" friction="0"/>
  </joint>
  <joint name="wrist_2_joint" type="revolute">
    <parent link="wrist_1_link"/>
    <child link="wrist_2_link"/>
    <origin rpy="1.570796327 0 0" xyz="0 -0.1157 -2.373046667922381e-11"/>
    <axis xyz="0 0 1"/>
    <limit effort="56.0" lower="-6.283185307179586" upper="6.283185307179586" velocity="3.141592653589793"/>
    <dynamics damping="0" friction="0"/>
  </joint>
  <joint name="wrist_3_joint" type="revolute">
    <parent link="wrist_2_link"/>
    <child link="wrist_3_link"/>
    <origin rpy="1.570796326589793 3.141592653589793 3.141592653589793" xyz="0 0.0922 -1.891053610911353e-11"/>
    <axis xyz="0 0 1"/>
    <limit effort="56.0" lower="-6.283185307179586" upper="6.283185307179586" velocity="3.141592653589793"/>
    <dynamics damping="0" friction="0"/>
  </joint>
  <link name="ft_frame"/>
  <joint name="wrist_3_link-ft_frame" type="fixed">
    <parent link="wrist_3_link"/>
    <child link="ft_frame"/>
    <origin rpy="3.141592653589793 0 0" xyz="0 0 0"/>
  </joint>
  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
  <link name="base"/>
  <joint name="base_link-base_fixed_joint" type="fixed">
    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
    <origin rpy="0 0 3.141592653589793" xyz="0 0 0"/>
    <parent link="base_link"/>
    <child link="base"/>
  </joint>
  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
  <link name="flange"/>
  <joint name="wrist_3-flange" type="fixed">
    <parent link="wrist_3_link"/>
    <child link="flange"/>
    <origin rpy="0 -1.5707963267948966 -1.5707963267948966" xyz="0 0 0"/>
  </joint>
  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
  <link name="tool0"/>
  <joint name="flange-tool0" type="fixed">
    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
    <origin rpy="1.5707963267948966 0 1.5707963267948966" xyz="0 0 0"/>
    <parent link="flange"/>
    <child link="tool0"/>
  </joint>
</robot>

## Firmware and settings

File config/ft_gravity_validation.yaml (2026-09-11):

schema_version: 1
samples:
- recorded_at: '2026-09-11T02:02:38.067682+00:00'
  tcp_pose:
  - 0.647563838597484
  - -0.19678380194977238
  - 0.5117413588216676
  - -2.1567893284985726
  - 2.0920533999700863
  - -0.11118163445607195
  motion_during_sample:
    position_m: 3.125573189841865e-05
    angle_deg: 0.0010755006649763898
  raw:
    count: 601
    mean:
    - 1.9224467387687196
    - 11.958190703826956
    - 58.13533642595674
    - 1.7824765291181364
    - 2.0380052196339435
    - -0.18519366888519123
    std:
    - 0.05087247708750069
    - 0.03839779288515662
    - 0.10751626779879692
    - 0.0031130119034544334
    - 0.003121308869675355
    - 0.0042458467472160965
  compensated:
    count: 600
    mean:
    - -0.7949627119936529
    - 0.20221030321680164
    - -5.889723967097312
    - -0.03320743245004912
    - 0.02596543759932964
    - 0.18877535161846637
    std:
    - 0.05091753172331871
    - 0.03834007380113193
    - 0.10719314663051133
    - 0.0031149198047642625
    - 0.0031236918437503648
    - 0.00423510659984689
- recorded_at: '2026-09-11T02:05:38.611693+00:00'
  tcp_pose:
  - 0.6476093266103847
  - -0.1967489729252278
  - 0.511743071656178
  - -1.9157698626589275
  - 1.9142335893041067
  - 0.2819797664664365
  motion_during_sample:
    position_m: 5.829208740520637e-06
    angle_deg: 0.003112973454434256
  raw:
    count: 601
    mean:
    - 10.504092665557412
    - 20.538123885191347
    - 55.042155121464255
    - 1.0175922246256253
    - 2.337726935108153
    - -1.4104064326123138
    std:
    - 0.05557077238100308
    - 0.03592378038514138
    - 0.11525750865937663
    - 0.002625237649546842
    - 0.002759439520386506
    - 0.0048570175615507815
  compensated:
    count: 600
    mean:
    - -0.8689965921734624
    - 0.2460113945572472
    - -6.079095242709826
    - -0.07367857589069143
    - 0.02542625120163473
    - 0.24059030964560024
    std:
    - 0.05562629992768506
    - 0.035850968294620006
    - 0.11494413542774394
    - 0.002628963093111496
    - 0.002761290840191467
    - 0.004859606135098517
- recorded_at: '2026-09-11T02:06:20.177161+00:00'
  tcp_pose:
  - 0.6475751697446065
  - -0.19680610461777145
  - 0.5117732502984726
  - 1.4089851635690602
  - -1.19282448021919
  - 1.2470748984138769
  motion_during_sample:
    position_m: 1.1486409606523422e-05
    angle_deg: 0.002217987267351309
  raw:
    count: 418
    mean:
    - -14.596500023923452
    - -20.52597447846889
    - 30.141094722488035
    - 1.5239638684210515
    - -1.1644645526315784
    - 2.871015533492821
    std:
    - 0.04615897779154333
    - 0.05506330788588411
    - 0.09353190700486132
    - 0.0036873242583255815
    - 0.0033598408979697353
    - 0.004932389336766959
  compensated:
    count: 600
    mean:
    - 1.5044712035081704
    - -5.260652118561023
    - -5.913055001107969
    - 0.18684591486493546
    - 0.011629597554666086
    - -0.15959542069125027
    std:
    - 0.04736872086762293
    - 0.06286568413001715
    - 0.09362763377129941
    - 0.0037739216463328175
    - 0.0032725946486888077
    - 0.005177608989828506
- recorded_at: '2026-09-11T02:13:15.109182+00:00'
  tcp_pose:
  - 0.647568282461317
  - -0.19679175954826114
  - 0.5117257479181114
  - 1.4090406713313222
  - -1.1927129289597698
  - 1.2470025609061943
  motion_during_sample:
    position_m: 1.4146005269386559e-05
    angle_deg: 0.00782695723070093
  raw:
    count: 600
    mean:
    - -14.982463133333313
    - -19.319284518333333
    - 30.18908613500002
    - 1.4871674566666673
    - -1.1627510933333327
    - 2.931820496666667
    std:
    - 0.04259191611764169
    - 0.04031260208429029
    - 0.10513429721608508
    - 0.0033020146958267086
    - 0.0030313720476524927
    - 0.004087168657313057
  compensated:
    count: 419
    mean:
    - 1.112521044706016
    - -4.032206174136418
    - -5.860548770935872
    - 0.149469464629133
    - 0.013322686622242815
    - -0.09771705644457375
    std:
    - 0.04236671045249358
    - 0.04066068442971001
    - 0.10582507628036722
    - 0.0033295177545372007
    - 0.003073069350087046
    - 0.004100027407640563
  software_bias:
  - 0.0
  - 0.0
  - 0.0
  - 0.0
  - 0.0
  - 0.0
- recorded_at: '2026-09-11T02:18:44.940612+00:00'
  tcp_pose:
  - 0.6475992535924335
  - -0.19799359903424402
  - 0.5103930570369163
  - -1.6996603518421374
  - 1.7471065863089017
  - 0.5556874483169043
  motion_during_sample:
    position_m: 2.0893584249363544e-05
    angle_deg: 0.002029366618141095
  raw:
    count: 601
    mean:
    - 16.80428760232944
    - 25.94327526455906
    - 49.788854670549135
    - 0.2766154309484191
    - 2.283610024958402
    - -2.250108098169717
    std:
    - 0.04892676152381142
    - 0.031498944303544905
    - 0.10395463845817399
    - 0.0017604782558985057
    - 0.0017590960130336568
    - 0.003890796897532719
  compensated:
    count: 600
    mean:
    - -1.0342800861934587
    - 0.2238608527798416
    - -5.705854529941888
    - -0.07198623622383193
    - 0.002814689263100901
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

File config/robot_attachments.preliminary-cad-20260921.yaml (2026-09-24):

# Conservative, visual/collision-only first pass based on uploaded CAD and photos.
# It is intentionally separate from robot_attachments.yaml and is NOT a truth model
# for real-robot clearance decisions.
model_status: preliminary_cad_envelope_not_real_robot_validated
cad_models_dir: model/solidworks/end_effector
tool_yaw_deg: 270.0  # current +90° baseline, then operator-requested +180°
handeye_calibration: config/handeye_eye_in_hand_20260921.yaml
force_sensor:
  enabled: true
  diameter_mm: 126.0  # uploaded ATI mesh bounds
  height_mm: 50.0
  offset_mm: 0.0
adapter:
  enabled: false      # CAD connection plate origin is not yet registered to tool0
gripper:
  enabled: true
  # conservative envelope of the uploaded closed 2F-85 mesh: width, axial length, depth
  size_mm: [126.4, 166.3, 75.0]
  # provisional: 50 mm ATI thickness + 33 mm coupler
  offset_mm: 83.0
camera_bracket:
  width_mm: 50.0
  length_mm: null
camera_housing:
  # retains margin around the uploaded 195 x 136.5 x 160 mm proxy
  size_mm: [200.0, 200.0, 170.0]
camera_offset_tool0_m: [0.04849423522761702, 0.25202240709668144, 0.19931610726118562]
camera_rotation_source: handeye
self_collision_margin_mm: 40.0

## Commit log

2026-09-10 UR10 机械臂 + Robotiq 夹爪 电脑 ROS2 全流程控制教程
    核心：机械臂与夹爪走两条独立的电脑直控通道
    - 机械臂: ROS 话题 /ur_link/urscript → 30002 → URScript movel()
    - 夹 爪: TCP 192.168.1.3:63352 → Robotiq ASCII 协议(rq_set_pos 等)
    示教器全程不参与，不受 URCap 注入代码/缓存干扰。
    主要内容:
    - README: 总览、5 步快速开始、通道架构、五个必知坑、安全须知
    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
2026-09-10 新增 docs/08：ATI Net F/T 六维力传感器 + Mech-Eye 3D 相机接入（全部真机实测）
    力传感器 ATI Net F/T（192.168.1.2, SN 1106WNT072, 固件 2.0.12, 标定 SI-165-15）:
    - 发现过程：HTTP 网页 Server: NET-FT/1.0 + MAC 厂商查询
    - RDT 协议打通：UDP 49152，命令 12 34 00 <采样数>（实测 cmd 只能用 0x00）
    - 36 字节包布局逐字段确认并与 HTTP 快照对照:
    [0]rdt_seq [1]ft_seq [2]status [3..8]Fx Fy Fz Tx Ty Tz
    - 新增 scripts/ati_netft_node.py：发布 /ft_sensor/wrench (WrenchStamped)
    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
2026-09-10 checkpoint: 网页监控台(桥/页面/启动器) + 相机接入助手，改前已备份 mecheye 源码(见 ~/ur_learn/generated/backups)
2026-09-10 网页监控台: ROS→WebSocket 桥 + 相机画面/六轴力折线页 + 模拟相机
    新增 docs/10-网页监控台.md（架构/协议/实测结果/排查）
    修复（均为实测发现）:
    - websockets >= 14 API 变更: 无 send_str，跨线程改 run_coroutine_threadsafe
    - ws_handler 用 functools.partial 传 bridge（ServerConnection 上没有 bridge 属性）
    - _pcl_stats 误用 msg.offset，实际字段偏移在 msg.fields[i].offset
    - ATI 读取加截止时间: 持续短包会把 read() 卡死（曾把节点挂住）
    - ATI 自愈: RDT 是单目的地单播，被别的客户端抢走时自动重申请
    - setup_mecheye 序列号解析: GVCP 应答里厂商名出现两次，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
2026-09-10 新增交接文档 HANDOVER.md + 给 AI 接手者的 CODEX_PROMPT.md
    HANDOVER.md（交接唯一入口，384 行）:
    - 系统全貌: 设备参数/IP/端口全表(实测)、两条核心通道架构
    - 当前状态: 8 项已真机验证的能力(附验证方式) + 待办按优先级
    - 环境现状: 接手时正在跑的进程、重启/停止命令
    - 代码仓库地图: 每个文件干什么 + 外部依赖目录说明
    - 五条铁律: def 必须调用 / rq_activate 死锁 / base≠base_link / RDT 单播 / 改前备份
    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
2026-09-10 修正交接文档的进程状态描述: 改为状态无关写法
    背景: 监控台三件套被外部 SIGTERM 终止（端口释放、网页不可达），
    而 HANDOVER.md 原写接手时正在运行，与现场不符——
    文档与现场不一致正是最不该留给接手者的。
    改动:
    - HANDOVER.md §2: 标题改为进程状态会变，接手时先自己查一遍，
    给出 ss/ps 一眼看全的查法；补充别在多处重复起同一节点的经验
    - HANDOVER.md §7: 网页那条验证命令注明需先 start_dashboard.sh
    - CODEX_PROMPT.md: 同步强调不要相信任何应该还在跑
2026-09-10 接通真实相机网页采集并修复力曲线
2026-09-10 提高相机刷新并固定力曲线滚动窗口
2026-09-10 修复 ur_circle.py 画圆脚本: 修正两处会导致不动且不报错的问题
    ① 赋值语法: URScript 是 ，旧版 语法错误（本地手册验证 := 出现 0 次）
    ② 缺少函数调用: 旧版发裸脚本，被 ur_command_node 包 def 后不执行（铁律 1）
    → 改为 def circle() + 显式调用 circle()，发送走 ur_arm.send_script
    原版备份: ~/ur_learn/generated/backups/ur_circle.py.orig
2026-09-10 修复 ur_circle.py 画圆脚本: 修正两处会导致[不动且不报错]的问题
    ① 赋值语法: URScript 赋值是 =（本地手册验证，:= 出现 0 次），旧版 n := 0 语法错误
    ② 缺少函数调用: 旧版发裸脚本，被 ur_command_node 包成 def 后不执行（铁律 1）
    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
2026-09-10 feat: add synchronized UR10 digital twin
    [ur10_cell.urdf.xacro]
2026-09-10 机器人自身标定: docs/11 执行记录 + TCP 球拟合工具 + 运动学实测结论
    docs/11-机器人自身标定.md:
    - 清单总览: 5 项标定状态(负载⚠/置零→Codex/TCP工具就绪/力系变换待办/运动学❌)
    - 负载: 实测工具侧 6.56kg(力传感器 |F|=64.4N)、力臂 43mm; 待确认传感器是否在臂上
    - 置零: 实测公式 output=gage-bias, 正确步骤(bias=+gage), 教训: POST会400(表单默认GET)
    - 运动学: 同姿态对比 标称2.6mm vs 正号28.3mm vs 反号26mm → 手改失败,
    结论维持标称, 未来亚毫米用官方 ur_calibration
    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
2026-09-10 ur_arm.py: 支持负载标定（Arm(payload=, cog=) 自动注入 set_payload）
    URSscript 程序每次运行会重置负载（示例程序 set_payload(0.01)），
    所以负载标定必须在自己的注入脚本里也设置。构造 Arm 时给 payload 即自动
    在脚本开头加 set_payload(质量, 重心)。默认不设，行为不变。
    备份: ~/ur_learn/generated/backups/ur_arm.py.pre-payload
2026-09-10 负载标定落地: 装配确认(偏心相机+正装夹爪), 实测质量与重心写入代码
    装配: 法兰→ATI传感器→[偏心3D相机]+[正装夹爪]
    实测: 工具(相机+夹爪)=6.56kg(|F|=64.4N); 重心横向偏移(-31,+29,-5)mm(来自偏心相机)
    采用: set_payload(8.0, [-0.03,0.03,-0.06]) —— 6.56+传感器~1.5kg, 重心实测+估算
    ur_pick_place_full.py: PAYLOAD_MASS/PAYLOAD_COG 接线; 真机验证 set_payload 执行无错
2026-09-10 feat: add active force gravity calibration
2026-09-10 fix: require force stream before calibration motion
2026-09-10 fix: reject ill-conditioned force calibrations
2026-09-10 fix: scale force preflight sample threshold
2026-09-10 保存 ATI 重力标定数据与修正模型
    [ft_gravity_calibration.invalid-20deg.yaml, ft_gravity_calibration.mixed-18.yaml, ft_gravity_calibration.yaml]
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2026-09-10 分离项目情报与未解决问题
2026-09-14 Validate native TCP speed control
    [speedl-20260914-150037.csv]
2026-09-14 Validate bidirectional TCP speed control
    [speedl-20260914-150326.csv]
2026-09-14 fix: label disabled IK probe as experimental
2026-09-14 experiment: archive robot calibration working notes
2026-09-14 docs: publish validated robot calibration results
2026-09-14 experiment: archive failed gravity compensation calibration
2026-09-14 feat: add read-only UR safety monitor
    [dashboard-20260914-153249.csv]
2026-09-14 experiment: record post-camera safety state
    [dashboard-20260914-155736.csv]
2026-09-14 fix: disable unvalidated gravity compensation model
    [ft_gravity_calibration.yaml]
2026-09-14 experiment: index daily calibration evidence
2026-09-16 experiment: archive force calibration and taught-path evidence
    [dashboard-20260915-090327.csv, dashboard-20260915-112901.csv, downward-20260915.csv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]
2026-09-16 docs: hand over calibration failures and official control gates
2026-09-17 fix: extract and verify UR10 factory calibration
    [ur10_factory_calibration.yaml]
2026-09-17 docs: archive gravity data and prioritize hand-eye calibration
2026-09-17 feat: calibrate eye-in-hand camera with held-out validation
2026-09-17 feat: locate cube candidate beside calibration board
2026-09-17 experiment: archive guarded visual grasp and placement
    [dashboard-20260917-111540.csv, visual-descend-20mm-20260917.csv, visual-hover-20260917.csv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]
2026-09-18 feat: add stationary fingertip TCP calibration workflow
2026-09-18 docs: keep only current verified operations
2026-09-18 test: add current documentation guard
2026-09-18 feat: add current position-only pick-place example
2026-09-18 feat: add read-only UR state reader (lesson 2)
    读 30003 的 q_actual/tool_vector_actual/tcp_speed_actual 与 Dashboard 的
    robotmode/safetystatus/机型/序列号/版本，支持 --watch 与 --json。
    只读，绝不发送运动或夹爪命令。已真机实测。
    [dashboard-20260918-101242.csv]
2026-09-18 docs: record lessons 1-2, eight-lesson plan, and two P0 findings
    - docs/01 新增 §7 设备清单与三条通道、§8 示教器运动与状态读取
    （含两个实测要点：关节角是连续角；TCP 位姿随控制器 TCP 定义变化）
    - 八节课实施计划草案（逐节做法、前置依赖、L7 的 2D/3D 采集解耦开关）
    - HANDOVER 0A 增加课程进度表、两个 P0 发现、已排除嫌疑清单
    - NEXT_SESSION_PROMPT.md：新会话提示词（刻意写短）
2026-09-18 docs: add complete position pick-place demo flow
2026-09-18 docs+feat: 眼在手标定本轮问题汇总，以及自碰撞/线缆绞紧的离线门禁
    新增 experiments/2026-09-18-眼在手标定问题汇总.md，集中整理本轮踩到的 13 个问题，
    并附数值证据与修复状态。其中 3 个是硬件层面的：两次相机线缆被腕部绞紧、一次 3D 相机
    实体接触机械臂。
    主要修复：
    - 采集器补证据缺口：每个样本落全量机器人帧（robot_frames.json）与原始点云（cloud.npz），
    旧版只存摘要，事后无法离线复核。
    - 修正球坐标函数的平移语义（与 solvePnP 相反），并补两条"钉住约定"而非"只验自洽"的自检；
    原自检对整体语义反向是盲的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
2026-09-19 新增模型资产：UR10 CB3 视觉网格 + 末端执行器 CAD + 碰撞 URDF
    - meshes/ur10_cb3/*.dae：UR10 CB3 视觉网格 x7（ur_description 官方网格，Z_UP/米）
    - models/end_effector/：末端执行器.SLDASM 导出（SolidWorks 2021，STEP AP214
    + 4 个装配全局系 STL，含 2F85/3D相机/六轴力/连接1）
    - urdf/ur10_cell.collision.xacro：碰撞版 URDF，整条末端链挂 tool0 之下；
    clocking 角已参数化：xacro arg tool_yaw（弧度），tool0_to_ft_mount rpy="0 0 tool_yaw"
    [ur10_cell.collision.xacro, 末端执行器 - 2F85-CLOSED_20181108.step-1.STL, 末端执行器 - 3D相机-1.STL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]
2026-09-21 feat: add preliminary CAD end-effector RViz model
    [robot_attachments.preliminary-cad-20260921.yaml]
2026-09-22 feat: add guarded dynamic point-cloud grasp flow
2026-09-24 data: archive complete calibration and digital twin assets
    [base.stl, cad_attachment_0.stl, cad_attachment_1.stl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]
2026-09-24 refactor: consolidate CAD and collision models
    [robot_attachments.preliminary-cad-20260921.yaml, ur10_cell.collision.xacro, 末端执行器 - 2F85-CLOSED_20181108.step-1.STL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]
2026-09-28 feat: embed live CAD model in dashboard
2026-09-28 fix: drive dashboard model from RViz URDF transforms
    [base.stl, forearm.stl, shoulder.stl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]
2026-10-08 docs: 补充机械臂基础与各标定原理教程（含配图 assets 与 fetch 脚本）
2026-10-09 fix: harden UR10 capture and relative motion; archive board validation
2026-10-09 analysis: publish offline hand-eye audit and next capture requirements
    [detector-comparison.csv, pair-results.csv, pairs.csv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]
2026-10-16 feat: archive hard-pen TCP calibration and supervised writing prototype
2026-10-21 feat: archive gravity v2 experiments and filtered dashboard preview
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2026-10-27 Update direct camera mount model and MU ROS geometry snapshot
2026-10-27 feat: recalibrate eye-in-hand camera and integrate factory IK with bounded dashboard jogs
2026-10-27 fix: plan preview trajectories to the entered target and expose tracking frames
